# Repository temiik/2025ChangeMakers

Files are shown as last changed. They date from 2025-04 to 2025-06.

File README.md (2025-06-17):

This repository documents our journey in building an autonomous vehicle for the WRO Future Engineers 2024-25 challenge, using a hybrid approach with LEGO EV3 and Raspberry Pi for robust, real-time vision and control.

# 🛠️ Team Changemakers — WRO Future Engineers 2024-25 Documentation





**Team Members:**  
- Yesken Kairat, 16 — kairatyesken@gmail.com  
- Tolendi Temirlan, 16  
- Yusuf Mukhambetkaliev, 16  

**Location:** Kazakhstan, Kokshetau
**Contact:** kairatyesken@gmail.com

**Mission:**  
> We are Team Changemakers — passionate about robotics, innovation, and real-world engineering. Our goal is to build robust, intelligent autonomous vehicles that can adapt to any challenge.

---

## Table of Contents
- [Introduction](#introduction)
- [System Architecture](#system-architecture)
- [Hardware Overview](#hardware-overview)
  - [Chassis & Steering](#chassis--steering)
  - [Sensors](#sensors)
  - [Computing Units](#computing-units)
- [Software Overview](#software-overview)
  - [EV3dev & Raspberry Pi Setup](#ev3dev--raspberry-pi-setup)
  - [Communication (SSH)](#communication-ssh)
  - [Vision & Detection (OpenCV)](#vision--detection-opencv)
  - [Control Logic](#control-logic)
- [Algorithmic Details](#algorithmic-details)
  - [ROI (Region of Interest) Explanation](#roi-region-of-interest-explanation)
  - [Ultrasonic Centering](#ultrasonic-centering)
  - [Wall Avoidance with Camera](#wall-avoidance-with-camera)
- [Why We Switched: Arduino, EV3, and Pi](#why-we-switched-arduino-ev3-and-pi)
- [Potential Improvements](#potential-improvements)
- [Team & Contact](#team--contact)

---

## Introduction

Our robot is designed to autonomously navigate a WRO FE field, detect colored pillars and lines, avoid walls, and park precisely. We leverage the strengths of both the LEGO EV3 (for reliable motor and sensor control) and the Raspberry Pi (for advanced computer vision), combining them via a simple and robust SSH-based communication protocol.

---

## System Architecture

- **Front-wheel Ackerman steering** for realistic car-like movement.
- **Rear-wheel drive** for propulsion.
- **Raspberry Pi** handles all camera-based object and wall detection using OpenCV.
- **EV3 Brick** (running ev3dev) manages motors, ultrasonic sensors, and executes movement commands.
- **SSH socket communication** links the Pi and EV3, ensuring low-latency, reliable command transfer.

---

## Hardware Overview

### Chassis & Steering

- **Chassis:** Custom made by lego, adapted for WRO FE size constraints.
- **Steering:** Front-wheel Ackerman steering, providing realistic turning dynamics and improved maneuverability compared to differential drive.
- **Drive:** Rear-wheel drive, controlled via EV3 motors.

### ⚡ Power Management

- **EV3 Power:** Powered by standard LEGO EV3 battery (2200mAh Li-ion)
  - Powers both EV3 motors (drive and steering)
  - Powers ultrasonic sensors and color sensor
  - Provides stable voltage for reliable sensor readings
- **Raspberry Pi Power:** USB power bank (10000mAh)
  - Dedicated power source for stable computer vision
  - Powers the CSI camera module
  - Ensures clean signal processing

### 🔌 Connection Scheme

#### EV3 Configuration

| Port Type | Port Number | Component | Purpose |
|---|---|---|---|
| Input | 1 | Ultrasonic Sensor (Left) | Wall distance detection |
| Input | 2 | Ultrasonic Sensor (Right) | Wall distance detection |
| Input | 3 | Color Sensor | Turn detection |
| Input | 4 | Touch Sensor | Program start button |
| Output | A | Drive Motor | Main propulsion |
| Output | B | Steering Motor | Direction control |

#### Raspberry Pi Configuration

| Port | Connected To | Purpose |
|---|---|---|
| CSI Port | Camera Module | Vision input |
| USB-A | EV3 Brick | SSH communication |
| USB-C | Power Bank | Power input (5V) |
| GPIO | Fan | Cooling (optional) |

#### Power Distribution

| Component | Power Source | Voltage | Current Draw |
|---|---|---|---|
| EV3 Brick | EV3 Battery | 7.2V | 2200mAh |
| Motors | EV3 Battery | 7.2V | ~500mA each |
| Sensors | EV3 Battery | 5V | ~50mA each |
| Raspberry Pi | Power Bank | 5V | ~2.5A max |
| Camera | Raspberry Pi | 3.3V | ~250mA |

#### Communication Flow
```
Raspberry Pi (Vision Processing)
         ↓ 
    [USB Cable]
         ↓ 
   EV3 (Control)
         ↓
[Motors & Sensors]
```

### Sensors

- **Ultrasonic Sensors (EV3):** Mounted on both sides for precise centering between walls.
- **Color Sensor (EV3):** For counting turns
- **Button (EV3):** Starting the program
- **Camera (Raspberry Pi):** Wide-angle CSI camera for robust color and object detection.

### Computing Units

- **Raspberry Pi 4:** Runs Python 3, OpenCV, and all vision algorithms.
- **LEGO EV3 Brick:** Runs ev3dev (Debian-based OS), controls motors and sensors, receives commands from Pi with python

---

## Software Overview

### EV3dev & Raspberry Pi Setup

- **EV3dev** installed on the EV3 brick for full Linux compatibility and Python support. It gives opportunity to control all motors and sensors with **python 3.5**
- **Raspberry Pi** runs Raspbian OS with OpenCV and all necessary Python libraries for columns and wall detection
- **SSH keys** set up for passwordless communication between Pi and EV3.

### Communication (SSH)

- **Socket-based protocol:** The Pi opens a TCP socket to the EV3, sending simple string commands (e.g., `red,640,300`, `backup`, `prepare_green`).

**Example: Socket connection on Raspberry Pi**
```python
import socket
client = socket.socket(socket.AF_INET, socket.SOCK_STREAM)
EV3_IP = '10.42.0.3'  # EV3 IP address
PORT = 12345
client.connect((EV3_IP, PORT))
```

**Example: Socket server on EV3**
```python
import socket
HOST = '0.0.0.0'
PORT = 12345
server_socket = socket.socket(socket.AF_INET, socket.SOCK_STREAM)
server_socket.bind((HOST, PORT))
server_socket.listen(1)
print("Waiting for connection from Raspberry Pi...")
client_socket, _ = server_socket.accept()
print("Connected.")
```

- **EV3 listens** for commands, parses them, and executes corresponding motor/sensor actions.

### Vision & Detection (OpenCV)

- **LAB color space** is used for robust color detection, minimizing the effect of lighting changes.
- **Gaussian blur, erosion, and dilation** are applied to clean up the image and improve contour detection.
- **Contours** are extracted for pillars, lines, and walls.
- **ROI (Region of Interest):** Only relevant parts of the image are processed for each task, improving speed and reliability.

**Example: ROI extraction and mask creation (Raspberry Pi)**
```python
    import cv2
import numpy as np
# Assume frame is a BGR image from the camera
lab = cv2.cvtColor(frame, cv2.COLOR_BGR2LAB)
ROI = (0, 160, 1280, 560)  # x1, y1, x2, y2
lab_roi = lab[ROI[1]:ROI[3], ROI[0]:ROI[2]]
lower = np.array([50, 20, 20], dtype=np.uint8)
upper = np.array([255, 110, 140], dtype=np.uint8)
mask = cv2.inRange(lab_roi, lower, upper)
```

**Example: Sending a command from Pi to EV3**
```python
msg = "red,640,300"  # Example: detected red pillar at (640, 300)
client.sendall((msg + "\n").encode())
```

**Example: Receiving and handling a command on EV3**
```python
for line in sock_file:
    msg = line.strip()
    if msg == "backup":
        # Back up if wall is too close
        drive_motor.run_forever(speed_sp=400)
        sleep(1.0)
        stop()
    elif ',' in msg:
        color, x, y = msg.split(',')
        # Handle pillar avoidance logic
```

### 🔧 Physical Setup and Calibration

#### Camera Mounting
- Camera mounted at optimal height (15cm) for pillar detection
- Tilted slightly downward (15°) to better see nearby obstacles
- Wide-angle lens provides ~160° field of view

#### Sensor Positioning
- Ultrasonic sensors mounted parallel to ground
- Positioned at equal distances from center
- Height optimized to avoid floor reflections

#### Motor Configuration
- Drive motor geared for balance of speed and torque
- Steering motor calibrated for maximum 50° turn angle
- PID parameters tuned for smooth control

### Control Logic

- **Pillar avoidance:** The Pi detects red/green pillars and sends their coordinates to the EV3, which executes a PD-controlled avoidance maneuver.
- **Wall centering:** The EV3 uses ultrasonic sensors to keep the robot centered between walls.
- **Wall avoidance (camera):** The Pi detects black regions (walls) in the camera image and commands the EV3 to back up if too close.
- **Line detection:** (If used) The Pi detects colored lines for turn/parking logic.

---

## Algorithmic Details

### ROI (Region of Interest) Explanation

- **Why ROI?** Processing only the relevant part of the image (e.g., lower half for wall detection, center for pillars) reduces noise and increases speed.
- **How?** Each detection task (pillar, wall, line) uses its own ROI, defined as a rectangle in image coordinates.

### Ultrasonic Centering

- **How it works:** The EV3 reads both left and right ultrasonic sensors. If the difference is within a small tolerance, the robot is centered. Otherwise, the steering is adjusted to correct the position.

**Example: Ultrasonic centering on EV3**
```python
def adjust_to_center():
    left = ultrasonic_left.distance_centimeters
    right = ultrasonic_right.distance_centimeters
    tolerance = 3
    if abs(left - right) <= tolerance:
        center_steering()
    elif left < right:
        steering_motor.run_to_abs_pos(position_sp=-50, speed_sp=1000)
    else:
        steering_motor.run_to_abs_pos(position_sp=40, speed_sp=1000)
    print("Left distance:", left)
    print("Right distance:", right)
```

### Wall Avoidance with Camera

- **How it works:** The Pi analyzes the lower part of the image for large black regions (walls). If detected, it sends a `backup` command to the EV3.

**Example: Wall detection and backup command (Raspberry Pi)**
```python
BLACK_LOWER = np.array([0, 0, 0], dtype=np.uint8)
BLACK_UPPER = np.array([50, 128, 128], dtype=np.uint8)
lower_roi = lab[600:720, 0:1280]
    lower_mask = cv2.inRange(lower_roi, BLACK_LOWER, BLACK_UPPER)
    lower_area = np.sum(lower_mask > 0)
if lower_area > 20000:
    client.sendall(b"backup\n")
```

---

## Why We Switched: Arduino, EV3, and Pi

- **Previous Solution:** We initially used Arduino for motor and sensor control, but found it limiting for real-time vision and complex logic.
- **Why EV3?** The EV3 offers robust, reliable motor and sensor control, and is easy to program with Python via ev3dev.
- **Why Raspberry Pi?** The Pi is powerful enough for real-time image processing with OpenCV, and can easily communicate with the EV3.
- **Why not just one?** Combining both allows us to leverage the strengths of each platform: Pi for vision, EV3 for control.
- **Communication:** SSH and sockets provide a simple, reliable way to link the two systems, with minimal latency and easy debugging.

---

## Potential Improvements

- **Integrate IMU/Gyro** for more precise turns and drift correction.
- **Optimize vision pipeline** for even faster frame rates.
- **Add stuck detection** using image similarity or motor feedback.
- **Experiment with different camera positions** for improved detection of low or high obstacles.
- **Add TPU** such as coral USB from google to increase amount of FPS
---

**Acknowledgements:**  
Thanks to the WRO community and open-source contributors for inspiration and code samples.

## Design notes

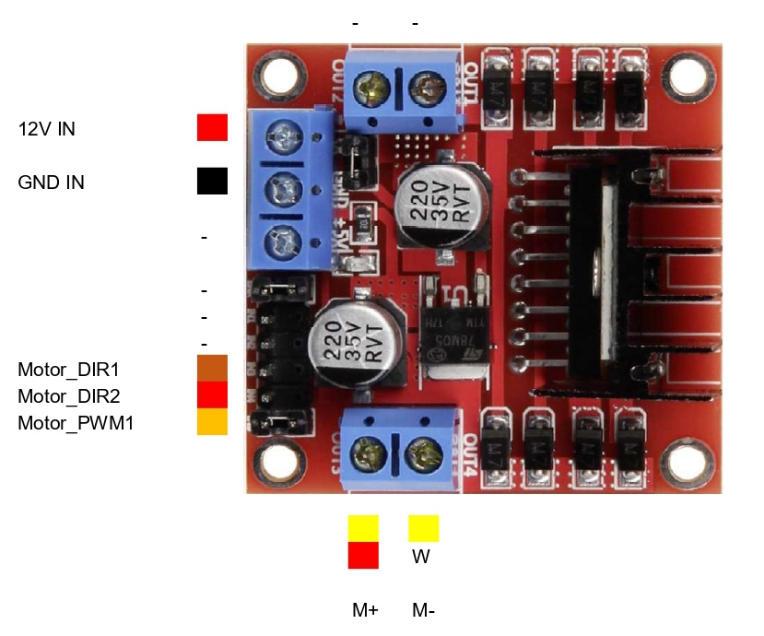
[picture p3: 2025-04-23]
schemes/pinouts_driver.jpg

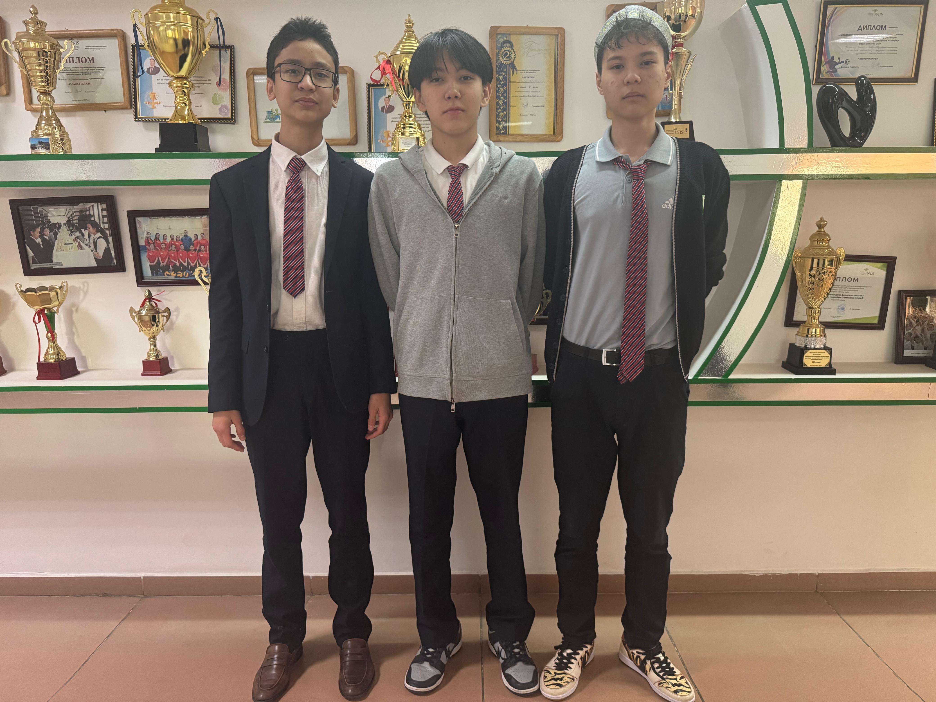
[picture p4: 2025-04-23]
t-photos/professional.jpeg

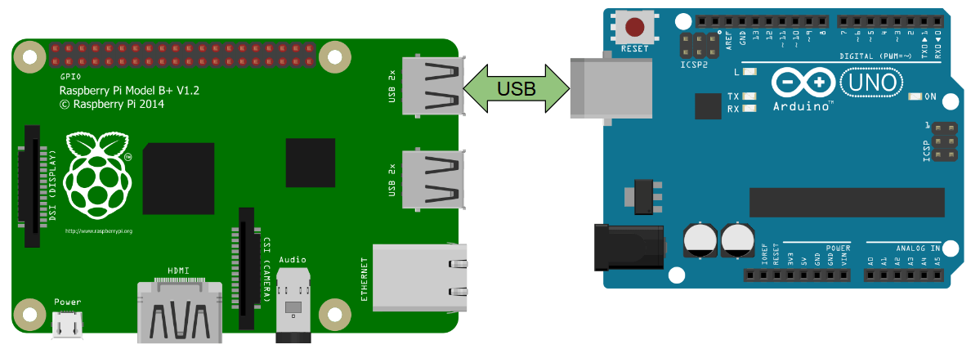
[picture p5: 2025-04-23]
schemes/Rasberrypiescheme.png

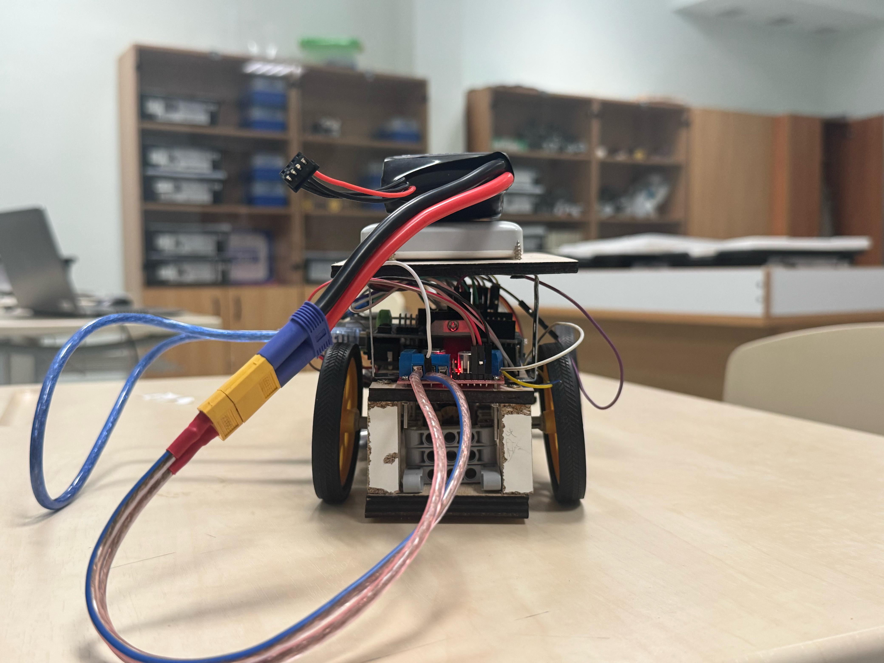
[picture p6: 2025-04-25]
v-photos/back.jpeg

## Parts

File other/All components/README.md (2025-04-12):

Raspberry pi 4B 8GB

Raspberry pi camera module v2

L298N motor driver

Motor 12B

Servo MG996R

Arduino uno

Laser ranger tracker GY-530 VL53LDK

Lipo battery 5000mAH 3S 100c

power reduction regulator DC-DC YH11060D 200Вт 12А

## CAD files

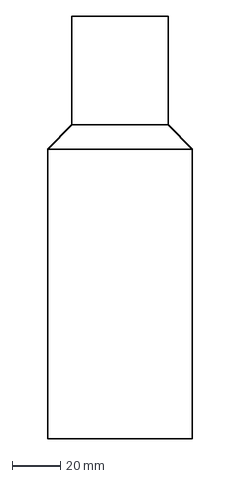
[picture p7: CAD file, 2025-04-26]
models/Untitled v8 v0.dxf
60.0 x 175.0 mm

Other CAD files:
models/Untitled v0.dxf

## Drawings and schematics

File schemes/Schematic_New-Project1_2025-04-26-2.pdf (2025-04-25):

## CN1VCC

# Raspberry pi 4B

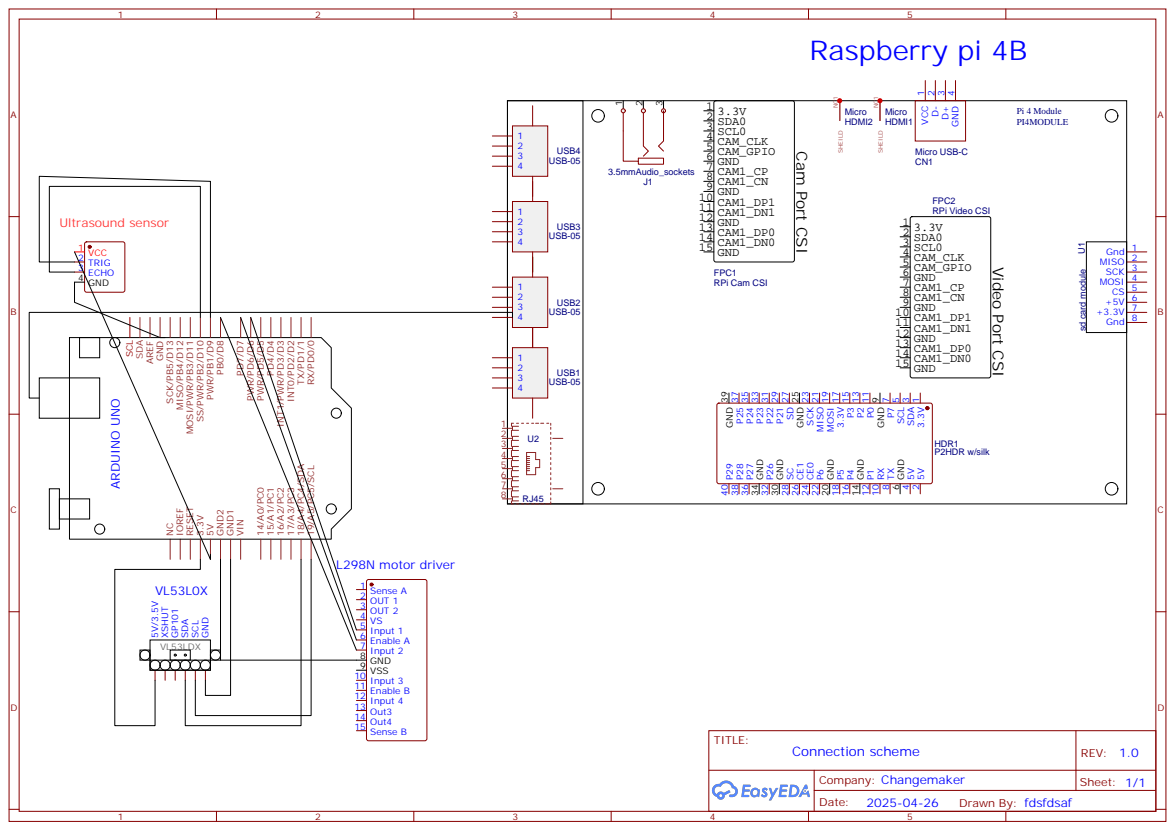
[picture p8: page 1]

9 P0 11 P2 13 P3 15 3.3V 17 MOSI 19 MISO 21 SCK 23 GND 25 SD 27 P21 29 P22 31 P23 33 P24 35 P25 37 GND 39 P29 40 P28 38 P27 36 GND 34 P26 32 GND 30 SC 28 CE1 26 CE0 24 P6 22 GND 20 P5 18 P4 16 GND 14 P1 12 RX 10
